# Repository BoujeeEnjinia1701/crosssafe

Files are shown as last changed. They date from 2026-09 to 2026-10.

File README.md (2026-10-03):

# CrossSafe

     

**Area:** Smart Cities · **TRL:** 3 of 9 (proof of concept on paper) · **Value-engineering target:** $350 USD (one assembly on an existing pole) · **Difficulty:** 3 of 5

A solar crossing beacon that detects a waiting pedestrian and flashes high-visibility lights to warn drivers at unsignalized crossings near schools and markets.

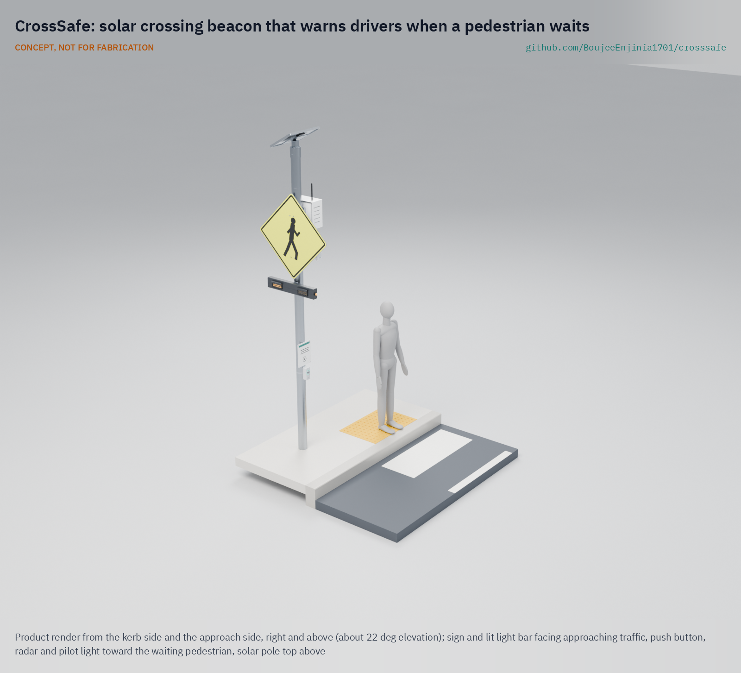
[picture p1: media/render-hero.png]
CrossSafe: solar crossing beacon that warns drivers when a pedestrian waits, product render


[Exploded render](media/render-exploded.png) · [Detail render](media/render-detail.png) · [Interactive 3D model](media/viewer.html) · [Concept blueprint (PDF)](media/concept-blueprint.pdf) · [General arrangement CRS-DWG-001 (PDF)](cad/drawings/CRS-DWG-001.pdf) · [Calculations](docs/04-calcs/01-sizing.md) · [Prototype build plan](docs/05-build-plan.md) · [Design decisions](docs/06-design-decisions.md) · [Review note](docs/REVIEW.md)

## Concept rationale

A driver yields when they see someone waiting, and a warning that appears only then is hard to ignore. CrossSafe copies the logic of the rectangular rapid flashing beacon (RRFB): two amber lights under the crossing sign that flash in a wig-wag pattern only when a pedestrian presses a button or a small radar, woken by a motion sensor, sees someone waiting at the kerb. One assembly stands on each side of the road; each has its own 20 W panel and LiFePO4 battery, and the two stay in step over a short radio link, so there is no mains connection and no cable across the road.

It is open and garage-buildable because the crossings that need it most are the ones no one will pay a signal contractor to fix. Every part is a standard sign, LED module, small solar kit, battery, IP65 box or common microcontroller, the firmware and wiring are published, and a local technician can repair it with hand tools. An open reference also lets road authorities, schools and researchers see exactly what the device does before they ask for approval to install it.

## Burning platform

About 1.19 million people die on the world's roads each year, and pedestrian deaths rose to about 274,000 in 2021, 23 % of the total, with nine in ten road deaths in low- and middle-income countries ([WHO, 2023](https://www.who.int/news/item/13-12-2023-despite-notable-progress-road-safety-remains-urgent-global-issue)). The UN General Assembly's target is to halve road deaths and injuries by 2030 ([WHO fact sheet](https://www.who.int/news-room/fact-sheets/detail/road-traffic-injuries)), and progress on pedestrians has gone the wrong way.

The problem is concentrated away from signals and after dark. In the United States, 74 % of the 7,314 pedestrians killed in 2023 died at locations that were not intersections, and 77 % died in the dark ([NHTSA, 2025](https://crashstats.nhtsa.dot.gov/Api/Public/ViewPublication/813727)). Pedestrian-activated beacons are one of the few low-cost measures with strong evidence: FHWA reports RRFBs can cut pedestrian crashes by up to 47 % and raise driver yielding to as high as 98 % ([FHWA](https://highways.dot.gov/safety/proven-safety-countermeasures/rectangular-rapid-flashing-beacons-rrfb)).

## Where it could be used

### By industry

| Industry | Use |
| --- | --- |
| Municipal roads and public works | Mid-block and uncontrolled crossings that do not qualify for a full signal |
| Education | School crossings used at the start and end of the day, often by children crossing alone |
| Markets and retail districts | Busy crossings on market days where traffic and pedestrian peaks coincide |
| Public transport | Crossings to bus and minibus stops on arterial roads |
| Hospitals, universities and campuses | Internal roads crossing between car parks, wards and buildings |
| Industrial sites and ports | Pedestrian crossings on plant roads shared with trucks and forklifts, off the public road network |

### By country or region

| Country or region | Why it matters there |
| --- | --- |
| Sub-Saharan Africa | The WHO African Region has 19 % of global road deaths with 15 % of the population and 3 % of the world's vehicles ([WHO Africa](https://www.afro.who.int/health-topics/road-safety)); walking is the main way many people travel and crossings rarely have signals |
| India | India accounts for about 10 % of road crash deaths worldwide, and most who die are pedestrians, cyclists and motorcyclists ([WHO India](https://www.who.int/india/health-topics/road-safety)) |
| South-East Asia | The WHO South-East Asia Region has the largest share of global road deaths, 28 % ([WHO, 2023](https://www.who.int/news/item/13-12-2023-despite-notable-progress-road-safety-remains-urgent-global-issue)) |
| Latin America and the Caribbean | About 145,090 road deaths in the Americas in 2021, with pedestrians, cyclists and motorcyclists rising from 39 % to 47 % of deaths since 2009 ([PAHO](https://www.paho.org/en/topics/road-safety)) |
| United States | 7,314 pedestrians killed in 2023, 74 % away from intersections ([NHTSA](https://crashstats.nhtsa.dot.gov/Api/Public/ViewPublication/813727)); RRFBs already have an FHWA interim approval ([IA-21](https://mutcd.fhwa.dot.gov/resources/interim_approval/ia21/index.htm)), so an open design could serve small towns and schools on tight budgets |
| United Kingdom | Pedestrians were 25 % of the 1,624 road deaths in Great Britain in 2023 ([Department for Transport](https://www.gov.uk/government/statistics/reported-road-casualties-great-britain-annual-report-2023/reported-road-casualties-great-britain-annual-report-2023)); local rules differ from US practice, so the flash pattern and sign are configurable |

## What sparked the idea

The starting point was a lapse in the rulebook. On December 21, 2017, FHWA terminated Interim Approval 11, which had allowed US agencies to install rectangular rapid flashing beacons, because the device had been patented and patented traffic control devices cannot be included in the MUTCD. The patents were then expressly abandoned, the RRFB concept passed into the public domain, and FHWA reinstated the device as Interim Approval 21 on March 20, 2018 ([FHWA IA-21](https://mutcd.fhwa.dot.gov/resources/interim_approval/ia21/index.htm)). A proven safety device had been off the list for three months over who owned it, and it came back only once it belonged to no one. CrossSafe takes that at its word: a beacon to the IA-21 pattern whose drawings, parts list and firmware are published so that any town, school or workshop can build and repair it.

## Problem

Pedestrians die at unsignalized crossings, and full traffic signals are costly and slow to approve. Static signs fade into the background, beacons that flash all day are ignored, and many crossings have no mains power nearby.

Full problem statement: [docs/01-problem.md](docs/01-problem.md)

## Concept

A solar crossing beacon that detects a waiting pedestrian and flashes high-visibility lights to warn drivers at unsignalized crossings near schools and markets.

One assembly stands on each side of the road: a crossing warning sign with a double-sided amber light bar and a pedestrian pilot light, a push button, a presence radar woken by a PIR sensor, and a pole-top enclosure with the battery, charger and controller under a ventilated sun shield and a 20 W panel. Both sides flash together for about 13 s per activation on a 7 m road. Only activation counts and faults are logged; no images or audio are recorded.

TRL 3 calculations ([CRS-CAL-001](docs/04-calcs/01-sizing.md)): 16.0 Wh/day at 300 activations, 7.7 days without sun, energy neutral at 1.05 peak sun hours, a 114.3 mm post at 45 % of yield in a 40 m/s gust, 53.9 °C inside the sun-shielded enclosure at 50 °C ambient, and $364 in parts per assembly on an existing pole ($728 per crossing), $14 over the $350 value-engineering target after the parts that make the design buildable and the visors and bezels on the LED heads. The existing-pole kit is limited to poles of 76 mm and larger, where the sign holds on paper at the assumed grip friction; smaller poles wait for a slip-torque test. Design decisions are recorded in [CRS-DDR-001](docs/decisions/0001-trl2-review-decisions.md), [CRS-DDR-002](docs/decisions/0002-recommendations-accepted.md) and [CRS-DDR-003](docs/decisions/0003-design-for-construction.md), and open ones, with the cost drivers, in the [design decisions register](docs/06-design-decisions.md). See the [design precis](docs/02-concept.md), [requirements](docs/03-requirements.md) and [general arrangement](cad/drawings/CRS-DWG-001.pdf).

## Key components

- Crossing warning sign, 750 mm, with a double-sided amber LED light bar (two heads per face)
- Accessible push button, a pedestrian pilot light, and a 24 GHz presence radar (presence only) switched on by a PIR sensor
- 20 W solar panel, MPPT charger and 12.8 V 12 Ah LiFePO4 battery
- Controller on the FieldNode radio core, with LED drivers and a LoRa link that keeps both sides in step
- IP65 pole-top enclosure under a ventilated sun shield
- Eight identical keyed pole saddles with stainless bands for an existing pole of 76 mm or larger (smaller poles wait for a slip-torque test of the saddle's grip), or a 114.3 mm post with an anti-rotation bolt where none exists

The working bill of materials is in [bom/bom.csv](bom/bom.csv).

## Building the prototype

The [prototype build plan](docs/05-build-plan.md) (CRS-BLD-001) shows how to make and fit every component of one assembly, the existing-pole kit, on a 3.7 m test post, with a making sketch for each made part, close-ups of the joints and a picture for every assembly step. Every part on the pole is held the same way: an aluminium saddle with a keyed V sits on the pole, a stainless band runs round the pole and across the saddle's front, and the part bolts to the saddle over the band. The work is sawing, drilling, tapping and folding aluminium bar and sheet, one small steel weldment, and wiring bought modules. It is a plan, not yet built; building to it is TRL 4 work.

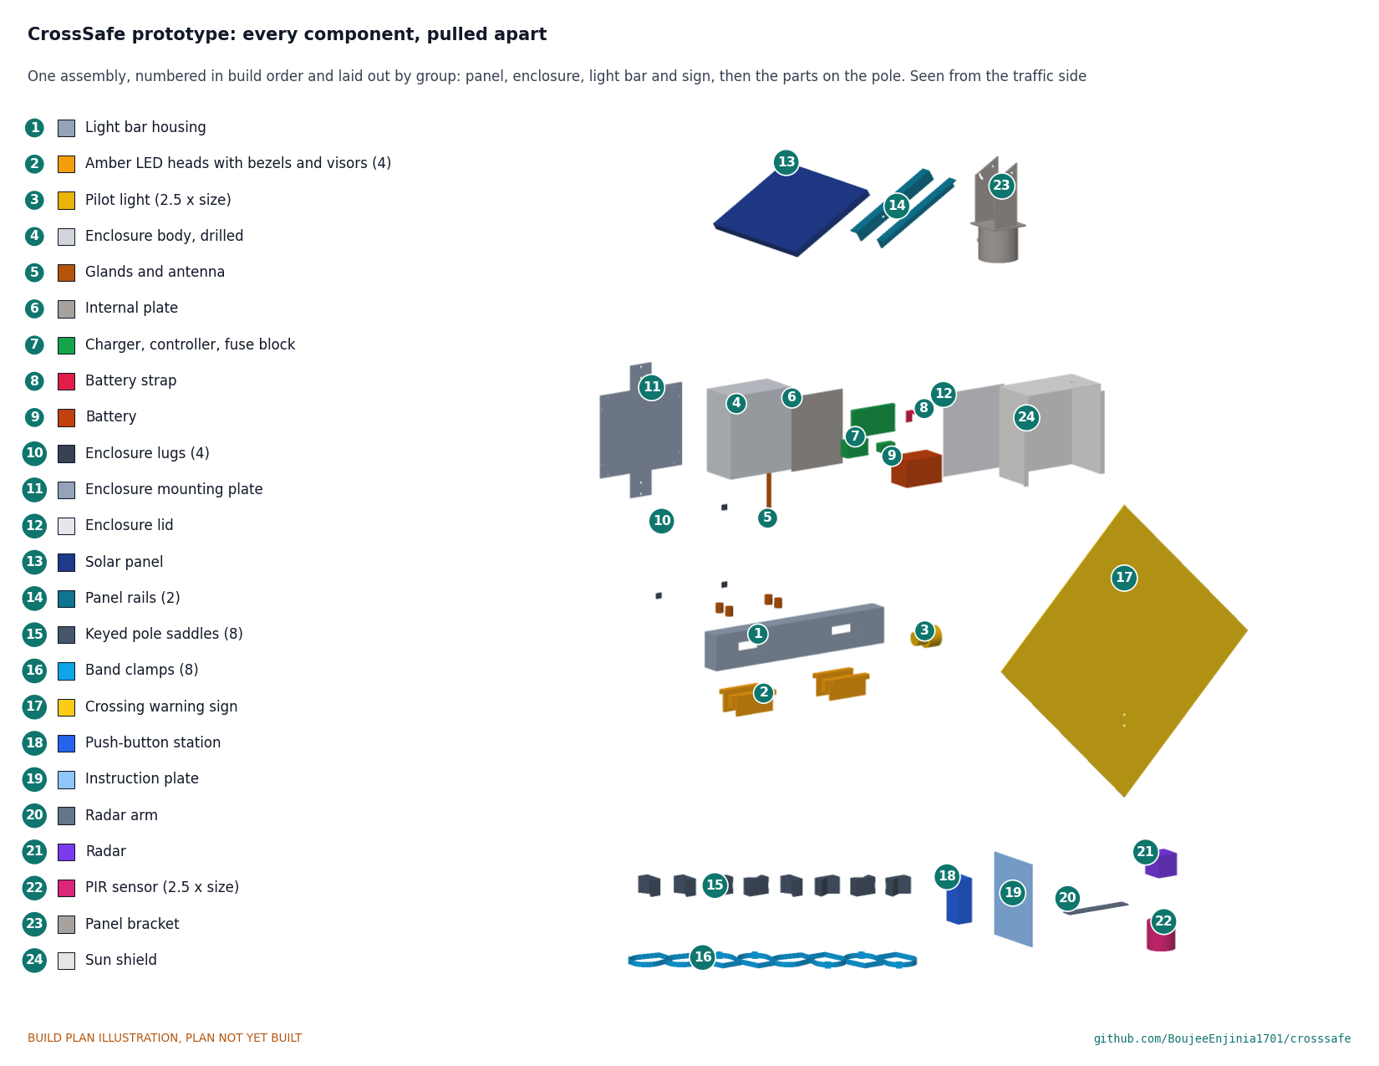
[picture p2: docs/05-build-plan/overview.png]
CrossSafe prototype: every component pulled apart and numbered in build order


## Safety

> A research prototype; traffic control devices must meet local standards and road authority approval before use on a public road. Pedestrians must still check that drivers have stopped. Lithium cells can overheat, vent and burn. Use protected cells or LiFePO4, fuse every pack, charge only within the cell maker's limits and never leave a first build charging unattended. Street furniture and pole mounts must be installed only with the asset owner's permission, by trained crews, with fall protection and traffic management as local rules require. The post, clamps, footing or host pole must pass a wind load check by a qualified engineer before installation; sign and panel edges are sharp.

## Repository layout

| Folder | Contents |
| --- | --- |
| `docs/` | Problem, concept, requirements, calculations and design decisions |
| `cad/src/` | build123d Python source, the source of truth for all geometry |
| `cad/step/`, `cad/stl/` | Exported models for FreeCAD, other CAD tools and printing |
| `cad/drawings/` | 2D sketches and dimensioned drawings |
| `bom/` | Bill of materials |
| `electronics/` | KiCad schematics and PCB layouts |
| `firmware/` | Microcontroller code |
| `media/` | Renders, perspectives and photos |
| `build-log/` | Dated prototyping notes |

## Documentation

Controlled documents follow the portfolio [documentation standard](.kit/STANDARDS.md). Each carries a document ID (CRS-PRC-001 for the precis), a version and a revision history. Branded PDFs are built with `python .kit/render.py` and attached to GitHub Releases when a document is tagged, for example `CRS-PRC-001/v1.0`.

## Credits

Designed by Amish Chadha. See [CONTRIBUTORS.md](CONTRIBUTORS.md) for roles. To cite this design, use [CITATION.cff](CITATION.cff) (GitHub shows it as "Cite this repository").

AI assistance (Claude) was used to accelerate concept renders, prototype documentation and first-pass sizing calculations. Design direction and all decisions are Amish Chadha's, recorded in this repository's decision records (`docs/decisions/`).

## Licenses

- **Hardware** (CAD, drawings, BOM, electronics): [CERN-OHL-S v2](LICENSE)
- **Software** (firmware, scripts, notebooks): [MIT](LICENSE-SOFTWARE)

A project of the [Design Molecule](https://designmolecule.com) lab.

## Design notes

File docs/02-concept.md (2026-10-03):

---
doc_id: CRS-PRC-001
title: CrossSafe design precis
project: CrossSafe
doc_type: Design precis
version: "0.8"
status: Draft
date: '2026-10-02'
author: Amish Chadha
license: CERN-OHL-S-2.0
revisions:
- version: "0.1"
  date: '2026-09-25'
  author: Amish Chadha
  change: Initial scaffold
- version: "0.2"
  date: '2026-09-25'
  author: Amish Chadha
  change: TRL 2 concept (how it works, components, first-order numbers, safety, open questions)
- version: "0.3"
  date: '2026-09-25'
  author: Amish Chadha
  change: TRL 3 update; design choices adopted for TRL 3 work (CRS-DDR-001), PIR gating, pilot light, 114.3 mm post, numbers from CRS-CAL-001, model and drawing CRS-DWG-001
- version: "0.4"
  date: '2026-09-25'
  author: Amish Chadha
  change: Recommendations accepted by Amish (DDR-002)
- version: "0.5"
  date: '2026-09-30'
  author: Amish Chadha
  change: Constructable design (CRS-DDR-003) with keyed saddles and bands for every part on the pole, mounting plate, radar arm, panel bracket and rails; numbers from CRS-CAL-001 v0.3
- version: "0.6"
  date: '2026-10-01'
  author: Amish Chadha
  change: Budget treated as a value-engineering target
- version: "0.7"
  date: '2026-10-02'
  author: Amish Chadha
  change: "Decisions of 2026-10-02: existing-pole kit limited to 76 mm and up until a slip-torque test; panel socket for free-topped 114 mm poles; first pilot partner candidate"
- version: "0.8"
  date: '2026-10-02'
  author: Amish Chadha
  change: Bezels and visors on the LED heads; pole range 76 to 114.3 mm; cost $364.00 per assembly
---

# CrossSafe design precis

## Summary

CrossSafe is a pair of pole-mounted, solar-powered warning beacons, one on each side of an unsignalized crossing. When a pedestrian presses the button or a small radar sensor sees someone waiting at the kerb, both assemblies flash two amber lights per face under the crossing warning sign for about 13 s, and a small pilot light confirms to the pedestrian that the warning is on. Each assembly runs from a 20 W panel and a 12.8 V 12 Ah LiFePO4 battery, a low-power PIR sensor switches the radar on only when something moves nearby, and the two sides stay in step over a short LoRa link, so no trench or cable across the road is needed. The TRL 3 calculations (CRS-CAL-001) give 16.0 Wh/day of use at 300 activations, 7.7 days without sun, and $360.00 in parts for one assembly on an existing pole, $10.00 over its budget after the parts that make the design buildable (CRS-DDR-003). A ventilated sun shield keeps the battery below its discharge limit, and an anti-rotation bolt (new posts) or keyed saddles (existing poles) stop the sign turning in a storm; only poles under about 70 mm remain at risk.

The concept follows the rectangular rapid flashing beacon (RRFB), which FHWA lists as a proven safety countermeasure ([FHWA](https://highways.dot.gov/safety/proven-safety-countermeasures/rectangular-rapid-flashing-beacons-rrfb)), and uses the US Interim Approval IA-21 as its reference for light size, flash pattern, night dimming and the optional pilot light ([FHWA IA-21](https://mutcd.fhwa.dot.gov/resources/interim_approval/ia21/index.htm)). It is an open reference design, not a certified traffic control device.

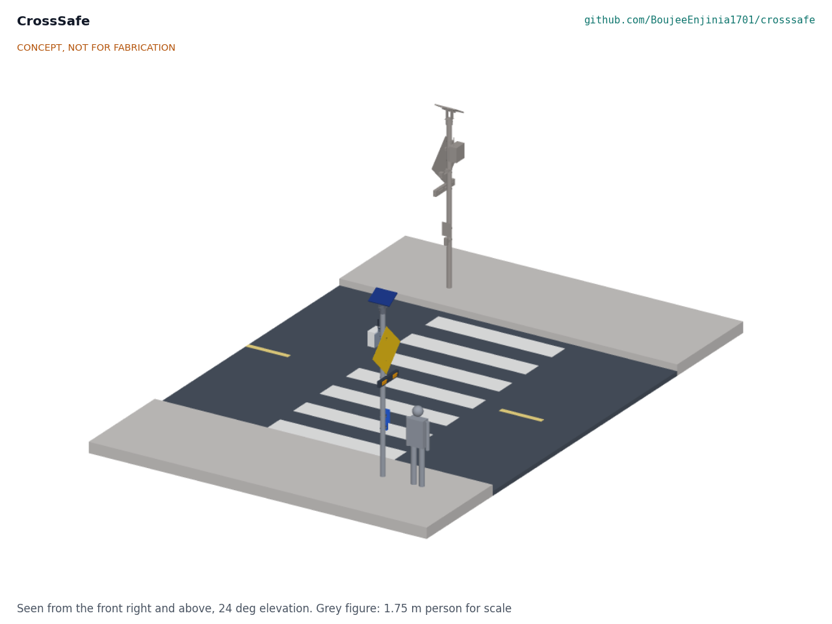
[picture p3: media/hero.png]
Figure 1. Hero render: one CrossSafe assembly on the near sidewalk of a 7 m two-lane crossing, the far-side assembly in grey, and a 1.75 m person for scale.


## How it works

1. **Idle.** The controller sleeps with its radio listening, the button is armed, and a PIR sensor watches for movement near the kerb. When the PIR sees motion it switches on the radar, which watches a waiting zone of about 1.5 x 2 m; the radar goes off again when nothing has moved for a set time. Passive detection can be switched off where it is not allowed. The battery charges from the panel.
2. **Trigger.** A button press, or a person detected in the waiting zone for 1 s or more, wakes the controller.
3. **Synchronize.** The controller sends a short LoRa packet to the far-side assembly (and listens for the same from it). Both start flashing within 48 ms, or 244 ms if two packets are lost (CRS-CAL-001).
4. **Warn.** Two amber heads per face flash in the IA-21 wig-wag sequence, 75 sequences per minute, for the site's set time (crossing length / 0.9 m/s + 5 s, 12.8 s for 7 m), dimmed at night. A new trigger extends the time. The pilot light on the kerb end of the light bar confirms to the pedestrian that the warning is on, and the button gives a click and a tactile pulse.
5. **Log.** The controller counts activations and records faults and battery state. It stores no images or audio; the radar reports presence only.

Figure 2 shows the daily energy flow and Figure 3 the parts. The general arrangement is drawing CRS-DWG-001 (`cad/drawings/`), generated from the parametric model `cad/src/model.py`.

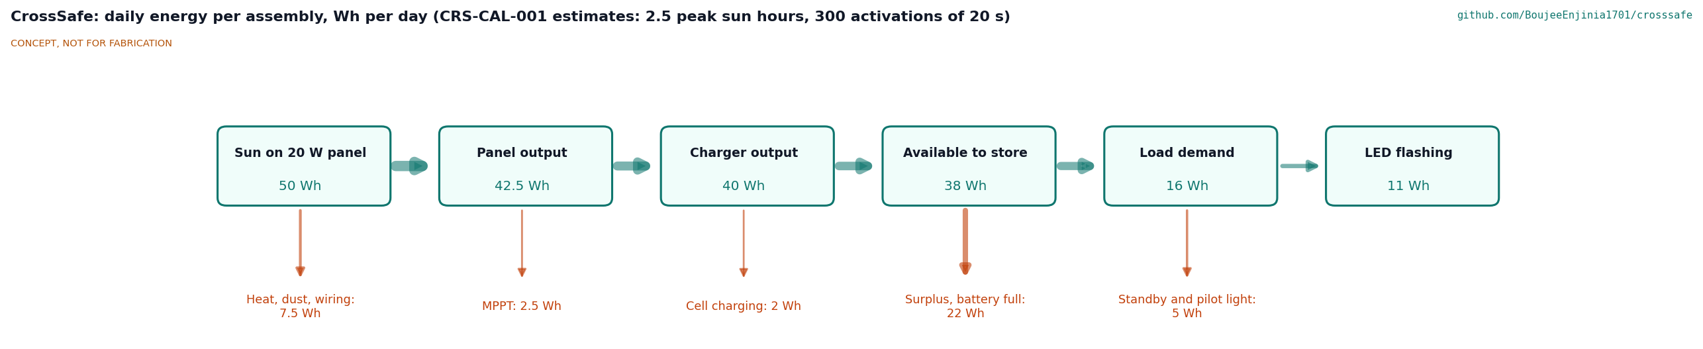
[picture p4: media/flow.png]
Figure 2. Daily energy flow for one assembly, Wh per day. All values are CRS-CAL-001 estimates (2.5 peak sun hours, 300 activations of 20 s).


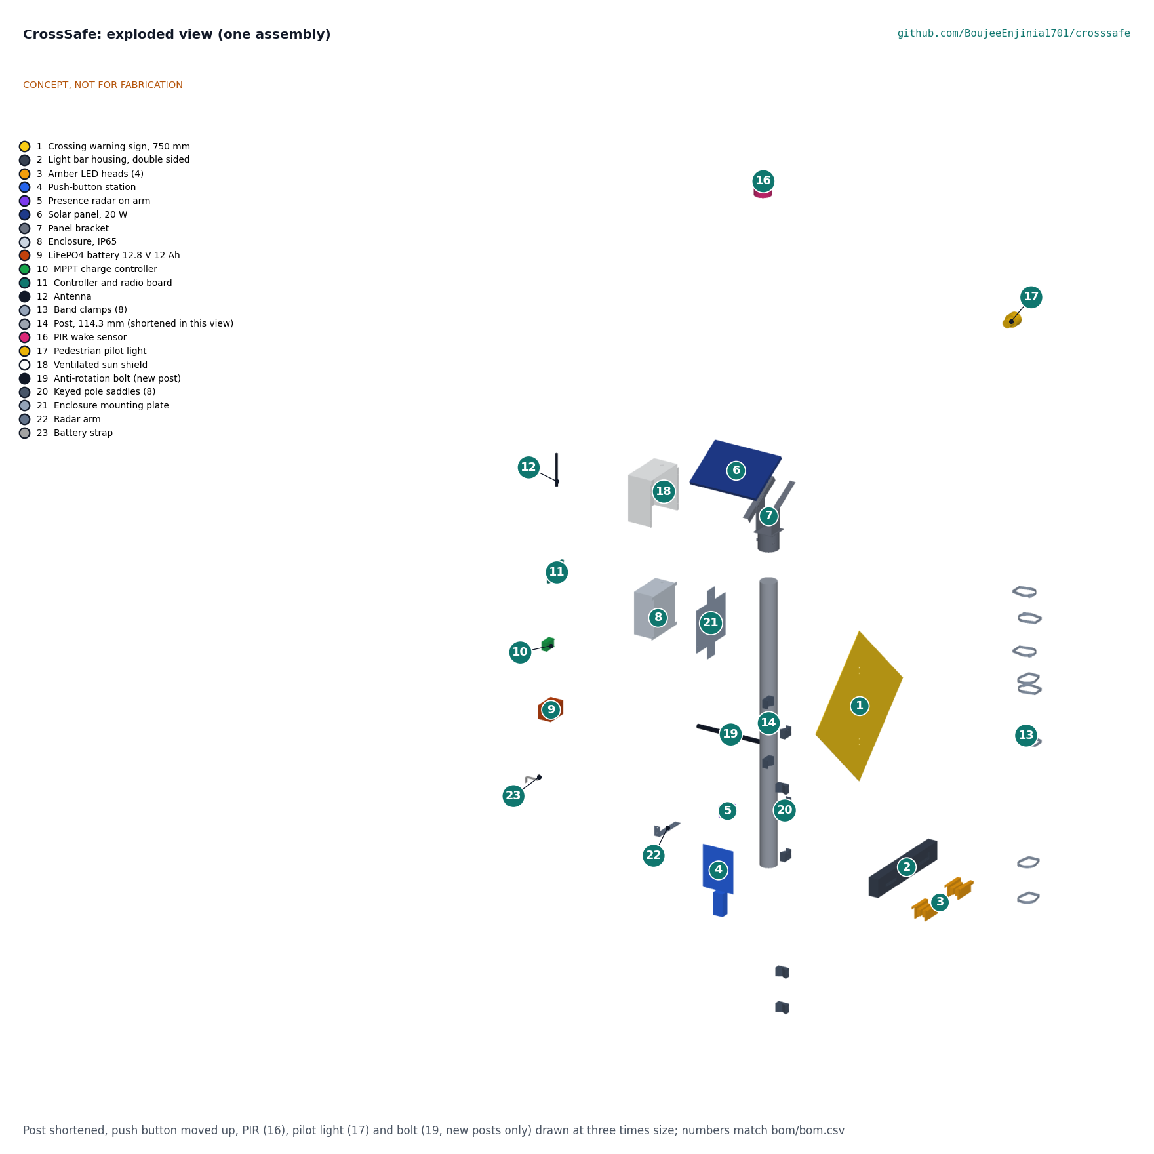
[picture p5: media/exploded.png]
Figure 3. Exploded view of one assembly; callout numbers match .


## Main components

Table 1. Components of one assembly. Numbers match the exploded view and `bom/bom.csv` (line 15, wiring, glands and fixings, has no callout). Each part is made and fitted as the build plan CRS-BLD-001 (`docs/05-build-plan.md`) shows.

| No. | Component | Concept choice |
| --- | --- | --- |
| 1 | Crossing warning sign | 750 mm diamond, retroreflective, local sign design |
| 2 | Light bar housing | Folded 2 mm aluminium channel with a screwed bottom cover and riveted end caps, double sided, 720 x 130 x 70 mm, bottom at 2.1 m |
| 3 | LED heads (4) | Amber, 140 x 62 mm lens (127 x 51 mm minimum), two per face, with daylight and night levels; each has a bezel frame and a 26 mm hood visor with a drip lip, bought with the head |
| 4 | Push-button station | Vandal-resistant piezo button with acknowledgement tone and tactile arrow, instruction plate, at about 1.0 m |
| 5 | Presence radar | 24 GHz presence sensor on the radar arm (22) at 2.6 m, aimed at the waiting zone, powered only when the PIR sees motion |
| 6 | Solar panel | 20 W monocrystalline, about 500 x 360 mm, tilted about 30 degrees toward the equator |
| 7 | Panel bracket | Welded steel socket, cap and cheeks on the post top, with two aluminium rails and a 20 to 40 degree tilt slot |
| 8 | Enclosure | IP65 polycarbonate, 150 x 260 x 300 mm, membrane vent, internal plate, lug kit, 2.85 to 3.15 m, behind the post on its mounting plate (21) |
| 9 | Battery | LiFePO4 12.8 V 12 Ah (about 154 Wh) with internal BMS |
| 10 | Charge controller | Small MPPT controller with a LiFePO4 profile and low-temperature charge cut-off |
| 11 | Controller and radio board | FieldNode radio core (STM32WL-class LoRa module) in point-to-point mode, four LED drivers with night dimming, real-time clock, fault indicator |
| 12 | Antenna | Short whip on the enclosure roof |
| 13 | Band clamps | Eight 19 x 0.76 mm stainless bands with buckles, one at each saddle |
| 14 | Post | Existing pole first; where a new post is needed, 114.3 x 3.6 mm galvanized steel, 3.7 m above the sidewalk, 1.8 m in a 500 mm footing |
| 16 | PIR wake sensor | Low-power passive infrared sensor under the radar; switches the radar on |
| 17 | Pedestrian pilot light | Small amber light on the kerb end of the light bar, where local rules allow |
| 18 | Sun shield | Ventilated white aluminium shield over the enclosure roof and three walls, 25 mm air gap, open at the bottom |
| 19 | Anti-rotation bolt | M10 stainless bolt through the sign, the upper sign saddle and the post; new posts only |
| 20 | Keyed pole saddles | Eight identical aluminium blocks with a keyed 120 degree V, a band groove and two M8 holes; every part on the pole bolts to one; fit 76 to 114.3 mm poles (60 to 75 mm only after a slip-torque test) |
| 21 | Enclosure mounting plate | 4 mm aluminium, 350 x 300 mm with saddle tabs above and below; carries the enclosure lugs and the sun shield |
| 22 | Radar arm | 40 x 5 mm aluminium bar bent to an L, on its own saddle; radar on top, PIR underneath |
| 23 | Battery strap | Bent aluminium strip holding the battery on the enclosure floor |

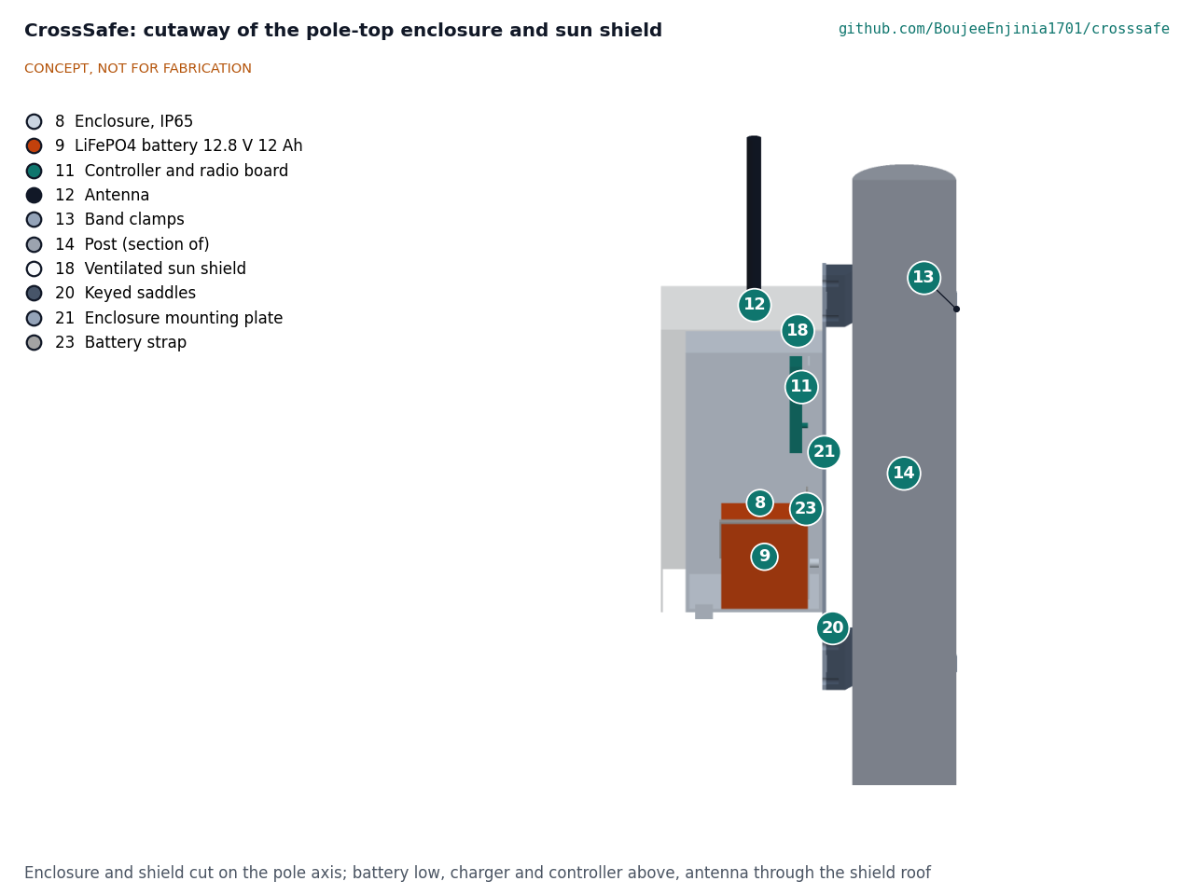
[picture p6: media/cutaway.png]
Figure 4. Cutaway of the pole-top enclosure and sun shield: battery low, charger and controller above, antenna through the shield roof.


## Key design choices

Each choice below was decided by Amish on 2026-09-25 by accepting the recommendations (CRS-DDR-001 and CRS-DDR-002).

- **RRFB-style amber beacons, not a signal (D4).** Amber warning lights with the standard sign ask drivers to yield; they do not claim to stop traffic, which keeps the device in a simpler approval class in most places. IA-21 is the baseline; the flash pattern is configurable for other jurisdictions.
- **Button plus passive detection, gated by a PIR (D2, D5).** The button is the reliable, accessible trigger; radar catches people who do not press it and can be switched off where passive detection is not allowed. The PIR keeps the radar off when nothing moves, which is what brings autonomy above 5 days. The radar reports presence only, which keeps images and audio off the device.
- **Radio sync instead of a cable (D6).** A LoRa point-to-point link avoids cutting the road. If the link drops, each side still flashes on its own trigger and reports a fault.
- **Own 12 V power system, FieldNode radio core (D7).** The LED load (up to about 26 W at the instant all four heads are lit) is far beyond the FieldNode power stage (6 W panel, 3.2 V cell), so CrossSafe uses a 12.8 V LiFePO4 battery with a built-in BMS. The controller reuses FieldNode's STM32WL-class radio and logging design. CellGuard, the lab's open BMS for 4 to 16 LiFePO4 cells, is a later option in place of the drop-in battery's closed BMS.
- **Existing poles first; 114.3 mm where a new post is needed (D3).** The band clamps and saddles are used only on poles of 76 to 114.3 mm until a slip-torque test confirms the keyed saddle's grip; a third saddle and band at the sign then brings 60 to 75 mm poles back (decided 2026-10-02). The prototype's panel socket fits free-topped poles of about 114 mm; a side-of-pole panel arm is designed once the pilot site's poles are known. The new-post variant meets the wind target with margin.
- **Pedestrian pilot light (D8).** IA-21 permits a small pilot light on the beacon or push button; it is included where local rules allow.
- **Sun shield on the enclosure (CRS-DDR-002).** A ventilated white shield cuts the enclosure's rise in full sun from 14.7 to 3.9 K when dusty, so the battery stays below its discharge limit and keeps charging on hot days. Placing the enclosure in the panel's shadow is to be considered when the bracket is detailed.
- **Anti-rotation detail (CRS-DDR-002).** An M10 through-bolt locks the sign and its upper saddle to a new post; on existing poles, where drilling needs the owner's consent, keyed saddles with serrated grip faces raise the clamp friction. Band tension and grip are to be measured at TRL 4, which is on hold.
- **One way of fixing everything to the pole (CRS-DDR-003).** Eight identical keyed saddles, each pulled onto the pole by a stainless band that runs across its front, carry the sign, light bar, button, instruction plate, radar arm and enclosure; each part bolts to its saddle over the band. The design is open for Amish's review.
- **Electronics high on the pole.** The enclosure bottom at 2.85 m and the panel at the top deter theft and keep cables out of reach.

## Key numbers (CRS-CAL-001)

The TRL 2 first-order estimates have been replaced by the TRL 3 calculation note CRS-CAL-001, which states every assumption and prints every figure from `docs/04-calcs/sizing.py`. The main results:

- **Flash time.** 12.8 s for a 7 m crossing; the energy case uses 20 s, enough for crossings up to 13.5 m.
- **Energy.** Each head is lit 25 % of each IA-21 sequence, so the LEDs use 10.99 Wh/day at 300 activations. Standby is 187 mW (4.49 Wh/day) with the PIR gating the radar. The daily load is 16.0 Wh, against 38.0 Wh stored in the worst month; break-even is 1.05 peak sun hours, and the battery refills from 20 % in 2.05 days at 5 peak sun hours.
- **Autonomy.** 122.9 Wh usable gives 7.7 days without sun, 5.4 days at -20 °C and 6.2 days at end of life.
- **Heat.** Unshielded, the enclosure would run 9.6 K (clean) to 14.7 K (dusty) above ambient in full sun and a dusty box would reach 64.7 °C at 50 °C ambient. With the sun shield the rise is 3.9 K: 53.9 °C inside at 50 °C ambient, and charging continues up to 41.1 °C ambient (R8 met on paper).
- **Latency and link.** 48 ms side to side, 244 ms with two retries; about 60 dB of link margin across the road with a bus in the way.
- **Wind.** A 40 m/s gust gives 3.52 kN·m at the base. The 114.3 x 3.6 mm post reaches 105 MPa, 45 % of S235 yield; an 88.9 x 4 mm post would reach 65 %. The sign's 175 N·m of torsion is carried by the through-bolt on new posts (12 % of bearing) and by keyed saddles on existing poles of 76 mm and larger, which hold at an assumed grip friction of 0.4 (R9); smaller poles wait for a slip-torque test. A 500 mm footing needs about 1.8 m of embedment in clay (screening).
- **Cost.** Value-engineering target: $350 per assembly on an existing pole (a hypothetical control target, not a limit). Estimated cost of the constructable design: $364.00 per assembly ($14.00 over the target) and $728.00 per crossing ($28.00 over the $700 target); $437.00 and $874.00 with new posts (see `bom/bom.csv`). Cost drivers and savings worth trying are in the Value engineering section of `docs/06-design-decisions.md`. The $750 value-engineering target for a two-sided site trial applies when a trial starts (on hold with TRL 4).

## Safety

> **Safety:** CrossSafe is a research prototype. A traffic control device must meet local standards and have road authority approval before use on a public road. A beacon that fails dark, flashes when no one is there, or gives pedestrians false confidence can cause harm; pedestrians must still check that drivers have stopped.

> **Safety:** Lithium cells can overheat, vent and burn. Use LiFePO4 with a BMS, fuse the battery output close to the terminal, charge only between 0 and 45 °C cell temperature, and shade the enclosure. Never charge a damaged or swollen battery.

> **Safety:** Installing on a pole next to live traffic is work at height and work in the road. Use trained crews, traffic management and fall protection as local rules require, keep clear of overhead power lines, and mount only with the asset owner's permission. A post, sign or panel that falls can kill. CRS-CAL-001 is a screening check only: clamp torsion is at risk on poles under about 70 mm, and a qualified engineer must check the post, clamps, footing or host pole to the local code before installation.

> **Safety:** Sign and panel edges are sharp and heavy; handle with gloves and a second person.

## Open questions

- [ ] Pilot jurisdiction and its rules for beacon color, flash pattern, sign design and mounting height. First candidate to approach (2026-10-02): a United States city traffic engineering department with a Safe Routes to School or Vision Zero programme, in a North Texas city near the team; nothing is agreed.
- [ ] Measured LED head power and intensity for the chosen modules, and whether 6 W per head is enough in full sun.
- [ ] Radar false-trigger rate with passing pedestrians, cyclists, animals and rain.
- [ ] Radio range and reliability across the road with parked vehicles and buses in the path, and licence-free band rules in the pilot country.
- [ ] Measured enclosure temperature in full sun with the shield fitted, and whether the enclosure can sit in the panel's shadow (CRS-CAL-001, section C).
- [ ] Measured band tension and keyed saddle grip (a slip-torque test), which must pass before the existing-pole kit is used below 76 mm with a third saddle and band (R9; CRS-DDR-002, N1, decided 2026-10-02); host pole checks by the owner; local foundation design.
- [ ] Whether the pedestrian-facing confirmation light is allowed locally.

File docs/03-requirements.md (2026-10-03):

---
doc_id: CRS-REQ-001
title: CrossSafe requirements
project: CrossSafe
doc_type: Requirements
version: "0.8"
status: Draft
date: '2026-10-02'
author: Amish Chadha
license: CERN-OHL-S-2.0
revisions:
- version: "0.1"
  date: '2026-09-25'
  author: Amish Chadha
  change: Initial scaffold
- version: "0.2"
  date: '2026-09-25'
  author: Amish Chadha
  change: First measurable requirements for TRL 2, with status against the concept estimates
- version: "0.3"
  date: '2026-09-25'
  author: Amish Chadha
  change: TRL 3 status from CRS-CAL-001; R15 redefined to the existing-pole assembly (CRS-DDR-001 D1); R1, R9 and R11 updated for D3, D4 and D8
- version: "0.4"
  date: '2026-09-25'
  author: Amish Chadha
  change: Recommendations accepted by Amish (DDR-002)
- version: "0.5"
  date: '2026-09-30'
  author: Amish Chadha
  change: Status from CRS-CAL-001 v0.3 for the constructable design (CRS-DDR-003); R15 now not met on paper
- version: "0.6"
  date: '2026-10-01'
  author: Amish Chadha
  change: Budget treated as a value-engineering target
- version: "0.7"
  date: '2026-10-02'
  author: Amish Chadha
  change: "R10 restated on 2026-10-02: existing-pole kit 76 to 114 mm until a slip-torque test, panel socket for free-topped poles of about 114 mm; no status changed"
- version: "0.8"
  date: '2026-10-02'
  author: Amish Chadha
  change: R9 met on paper for 76 to 114.3 mm poles; R10 and R15 figures updated (cost $364.00 per assembly)
---

# CrossSafe requirements

These requirements are checked by calculation in CRS-CAL-001 at TRL 3. Targets are still proposals, not yet validated with users or a road authority, and will be revised after co-design (see CRS-PRB-001). Where a local rule is stricter, the local rule wins. The design choices behind them were accepted by Amish on 2026-09-25 (CRS-DDR-001 and CRS-DDR-002).

The **design case** is a marked crossing on a two-lane road 7 m kerb to kerb, one CrossSafe assembly on each side, 300 activations of 20 s per day, 2.5 peak sun hours per day in the worst month, and an ambient range of -20 to +50 °C.

Table 1. Requirements and status at TRL 3 (CRS-CAL-001 v0.4, Table 5).

| ID | Requirement | Target | Verification (TRL 3 or later) | Status at TRL 3 |
| --- | --- | --- | --- | --- |
| R1 | Warning light geometry and pattern | Two amber rectangular indications per face, each at least 127 x 51 mm (5 x 2 in); the FHWA IA-21 wig-wag sequence at 75 flashing sequences per minute; pattern set in firmware for other jurisdictions; an optional pedestrian pilot light where allowed | Design review against the pilot jurisdiction's rules | Met by design (140 x 62 mm lenses) |
| R2 | Visibility | Indications distinguishable by a driver at 100 m or more in direct sun (IA-21 cites SAE J595 Class 1 yellow peak intensity) and not glaring at night (automatic dimming) | Photometric calculation from LED data; later field check | Not verifiable at TRL 3 (screening: about 3,939 cd per head) |
| R3 | Activation | Push button and passive presence detection; both sides of the road flash within 0.5 s of a trigger on either side | Timing budget; later bench test | Met on paper (48 ms; 244 ms with two retries) |
| R4 | Flash duration | Set per site from crossing length / 0.9 m/s + 5 s, adjustable 10 to 40 s; a new trigger while flashing extends the time | Firmware review | Met by design (12.8 s for 7 m) |
| R5 | Detection quality | Passive detection triggers for a person waiting 1 s or more in the waiting zone; false activations 5 % or fewer of all activations; missed waiting pedestrians 2 % or fewer | Site trial with manual counts | Not verifiable at TRL 3 |
| R6 | Autonomy without sun | 5 days or more of design-case use from a full battery | Energy calculation | Met on paper (7.7 days; 5.4 at -20 °C) |
| R7 | Energy balance | Energy neutral at 2.5 peak sun hours; recover from 20 % to full in 3 days or fewer at 5 peak sun hours | Solar yield calculation | Met on paper (break-even 1.05 h; recovery 2.1 days) |
| R8 | Environment | Enclosures and connectors IP65 or better; operate -20 to +50 °C ambient; battery charges only at 0 to 45 °C cell temperature | Datasheets and heat balance; later spray and thermal tests | Met on paper with the sun shield (53.9 °C inside at 50 °C ambient when dusty; charging to 41.1 °C ambient) |
| R9 | Structure | Post and clamps carry the sign and panel in a 40 m/s gust with stress 60 % or less of yield; new posts are 114.3 x 3.6 mm (CRS-DDR-001 D3); the sign cannot rotate on its pole (anti-rotation bolt on new posts, keyed saddles on existing poles, CRS-DDR-002) | Wind load calculation | **Met on paper for poles of 76 to 114.3 mm: post 45 % of yield and bolt 12 % of bearing; keyed saddles resist 191 N·m on a 76 mm pole against 175 N·m, at assumed friction and band tension** |
| R10 | Mounting | Fits the project's own post or an existing 76 to 114 mm pole with band clamps (60 to 75 mm poles only after a slip-torque test confirms the keyed saddle's grip, with a third saddle and band at the sign); the prototype's panel socket fits free-topped poles of about 114 mm; sign bottom at 2.1 m or more (or local rule); two-person crew installs one assembly in 2 h or less | Design review; later timed trial | Not verifiable at TRL 3 (fit met on free-topped poles of about 114 mm; install estimate 120 min, at the limit) |
| R11 | Accessibility | Push button 0.9 to 1.1 m above the walking surface, operable with 22 N or less, with an audible and tactile acknowledgement and a pedestrian-facing pilot light | Design review with disability groups | Met by design (button at 1.05 m), to be checked in co-design |
| R12 | Fail-safe behavior | Never flashes continuously; a fault (low battery, open LED, lost radio link) is shown on a maintenance indicator and logged; with the link lost, each side still flashes on a local trigger | Firmware review; fault injection later | Met by design |
| R13 | Privacy | No images or audio are recorded or leave the device; only activation counts, faults and battery state are logged or sent | Design review | Met by design |
| R14 | Theft and vandal resistance | Battery, charger and controller 2.8 m or more above the walking surface; security fasteners; no exposed cables below 2.5 m | Design review | Met by design (enclosure bottom 2.85 m; sensing head 2.515 m and up) |
| R15 | Affordable | Parts for one assembly on an existing pole $350 or less (the prototype `budget_usd` covers, CRS-DDR-001 D1); parts for a two-sided crossing on existing poles $700 or less. Crossings that need new posts are costed and reported, not held to this target | Priced BOM (`bom/bom.csv`) | **Over the value-engineering target by $14.00 per assembly ($364.00 against $350) and $28.00 per crossing ($728.00 against $700)**; new posts $437.00 and $874.00 |

## Requirements at risk or not verifiable

One requirement is over its value-engineering target on paper (R15, cost) and three need evidence that a paper study cannot give.

- **R15 over the value-engineering target after the design for construction (CRS-DDR-003).** The saddles, mounting plate, panel bracket, radar arm, battery strap and fixings that make every part buildable and fixed add $28.00, and the bezels and visors on the four LED heads add $4.00: the estimated cost of one assembly on an existing pole is $364.00 against the $350 target ($14.00 over), and of a crossing $728.00 against $700 ($28.00 over). The target is a hypothetical control target, not a limit; cost drivers and savings worth trying are in the Value engineering section of the design decisions register.

- **R9 met on paper on poles of 76 mm and larger.** The 114.3 x 3.6 mm post meets the stress target at 45 % of yield, and a 1,800 mm embedment in a 500 mm footing is a screening size. On new posts the M10 through-bolt stops the sign rotating with a wide margin. On existing poles the keyed saddles hold on poles of about 70 mm and larger at an assumed grip friction of 0.4, so R9 is met on paper for the 76 to 114.3 mm range the existing-pole kit is now limited to (decided 2026-10-02, CRS-DDR-002, N1). The friction and band tension are assumptions, and the 191 N·m resistance on a 76 mm pole is only 9 % above the 175 N·m load. A slip-torque test on the keyed saddle must confirm the grip before the kit is used below 76 mm, when a third saddle and band would bring 60 to 75 mm poles back. On existing poles the host pole must carry about 2.5 kN·m more at the sidewalk, which the owner must confirm.
- **R8 met on paper after the sun shield (CRS-DDR-002).** Unshielded, a dusty enclosure ran 14.7 K above ambient and reached 64.7 °C at 50 °C ambient; with the ventilated shield the rise is 3.9 K and the interior 53.9 °C, below the typical 60 °C discharge limit. The shield factor is borrowed, not measured.
- **R2, R5 and R10 are not verifiable at TRL 3.** R2 and R5 decide whether drivers respond and whether passive detection is trusted.
- **R6, not met at TRL 2, is now met on paper** after the PIR gating (D2).

## Assumptions

The full list is in CRS-CAL-001, Table 1. The main ones are:

- LED heads draw about 6 W each when lit in daytime and are lit 25 % of each IA-21 sequence; LED drivers are about 91 % efficient.
- Standby about 187 mW: radio in continuous receive and controller about 23 mW, 12 V quiescent about 13 mW, charger about 51 mW, radar 0.4 W on 25 % of the day under PIR gating.
- Solar system efficiency about 76 % from panel rating to energy stored (panel heat and dust 0.85, MPPT 0.94, cell charge 0.95).
- Walking speed of 0.9 m/s allows for children and older people; the US MUTCD basis is faster, and local rules decide.
- Gust wind speed of 40 m/s and a drag coefficient of 1.2 for every part; S235 steel for the post; band tension 1,000 N; keyed saddle grip friction 0.4; a ventilated shield passes 25 % of the solar gain.

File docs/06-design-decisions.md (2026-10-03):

---
doc_id: CRS-DEC-001
title: CrossSafe design decisions register
project: CrossSafe
doc_type: Design decisions register
version: "0.4"
status: Draft
date: '2026-10-02'
author: Amish Chadha
license: CERN-OHL-S-2.0
revisions:
- version: "0.1"
  date: '2026-09-30'
  author: Amish Chadha
  change: Register opened with the open decisions from the review note, CRS-DDR-001 to CRS-DDR-003 and the build plan work
- version: "0.2"
  date: '2026-10-01'
  author: Amish Chadha
  change: Budget treated as a value-engineering target
- version: "0.3"
  date: '2026-10-02'
  author: Amish Chadha
  change: "Amish approved the recommendations for all open decisions 1 to 8 on 2026-10-02 (CRS-DDR-003 accepted; existing-pole kit limited to 76 mm and up); moved to decisions made"
- version: "0.4"
  date: '2026-10-02'
  author: Amish Chadha
  change: "Value engineering figures updated for the head bezels and visors: USD 364.00, USD 14.00 over the target"
---

# CrossSafe design decisions register

Every design decision still to be made, and every decision made, in one place. Each decision is argued in full in its decision record under `docs/decisions/`; this register is the index Amish works from. The build plan (`docs/05-build-plan.md`) describes the design as it stands and does not list open decisions.

## Open decisions

None. All open decisions were decided on 2026-10-02.

## To confirm when parts are bought

| # | What to confirm | Why it matters | Source |
| --- | --- | --- | --- |
| 1 | The enclosure model: its internal plate and boss positions, its lug kit, and that the lid is on the 260 x 300 face away from the back | They set the internal plate layout, the lug holes in the mounting plate and the shield fit | CRS-DDR-003, P4 |
| 2 | The solar panel frame has a flat back lip at least 15 mm wide on its long edges | The rails bolt through it | CRS-DDR-003, P8 |
| 3 | Each LED head's flange covers a 128 x 50 mm window, its body is no deeper than 25 mm, and its screw pattern | They set the light bar windows and leave 16 mm between facing heads | CRS-DDR-003, P3 |
| 4 | The push-button station fixes to a flat face with two bolts 40 mm apart (or an adaptor plate is needed) | It bolts to a saddle's two tapped holes | CRS-DDR-003, P9 |
| 5 | The radar housing's two base screws are 50 mm apart and the PIR's neck is 12 mm or less | They set the radar arm's holes | CRS-DDR-003, P7 |
| 6 | The battery, charger and controller board fit the sizes in the build plan (151 x 95 x 98, 40 x 90 x 60, 180 x 100 mm) | The internal layout and the battery strap are drawn to them | CRS-DDR-003, P4 |
| 7 | The band and buckle reach 1,000 N of tension with the banding tool, and the keyed saddle's grip friction is about 0.4 | CRS-CAL-001 assumes both for the sign torsion; until a slip-torque test confirms them the existing-pole kit is limited to poles of 76 mm and larger (decided 2026-10-02) | CRS-CAL-001, [G6c] |
| 8 | The test post's top is square and open (or capped flush) so the bracket cap sits on it | The socket's cap rests on the pole's top edge | CRS-DDR-003, P8 |

## Value engineering

Value-engineering target: USD 350 (a hypothetical control target, not a limit). Estimated cost of the constructable design: USD 364.00 (USD 14.00 over the target). A crossing needs two assemblies: USD 728.00 against a target of USD 700; with new posts USD 437.00 and USD 874.00, which are costed and reported, not held to the target.

Main cost drivers: the eight keyed saddles in place of two (USD 18.00 more), the enclosure mounting plate (USD 8.00), the panel bracket (USD 6.00 more), the radar arm and battery strap (USD 3.00) and the fixings (USD 4.00 more) and the bezels and visors bought with the LED heads (USD 4.00), less the sign maker's brackets (USD 5.00) and the bought band brackets (USD 6.00). All prices are indicative until quoted at TRL 4.

Savings worth trying: a cheaper enclosure or sign quote, aiming at the USD 14.00 gap. The site-trial target of USD 750 for a two-sided crossing applies when a trial starts (on hold with TRL 4).

## Decisions made

| Date | Decision | Decided by | Record |
| --- | --- | --- | --- |
| 2026-09-25 | TRL 2 review items D1 to D9: `budget_usd` covers one assembly on an existing pole; PIR gating of the radar; existing poles first and a 114.3 x 3.6 mm post where a new one is needed; FHWA IA-21 baseline; button plus passive detection; LoRa side-to-side link; FieldNode radio core with CrossSafe's own 12 V power; pedestrian pilot light where allowed; no change to the pitch | Amish: "i accept all your recommendations, go with them across all repos." | CRS-DDR-001, CRS-DDR-002 |
| 2026-09-25 | $750 site-trial value-engineering target for a two-sided crossing, to apply when a site trial starts (on hold with TRL 4); `budget_usd` stays $350 | Amish, same instruction | CRS-DDR-002, O2 |
| 2026-09-25 | Ventilated sun shield on the enclosure (E1); anti-rotation bolt on new posts and keyed saddles on existing poles (E2); timed installation trial, on hold with TRL 4 (E3) | Amish, same instruction | CRS-DDR-002 |
| 2026-09-26 | CrossSafe chosen for the first batch of product renders | Amish | REVIEW 2026-09-26 |
| 2026-09-30 | Build plan format approved; open decisions kept in this register, not in the build plan | Amish: "this is the correct build plan ... this is a good quality document format. Extend this across all the other repos" | This register; CRS-BLD-001 |
| 2026-09-30 | Make the design physically buildable while drawing the build plan | Amish: "If you are realising that the design cannot be built as per concept - fix the design assumptions to match and be physically feasible as you draw the illustrations." | CRS-DDR-003 (changes accepted on 2026-10-02, below) |
| 2026-10-02 | Design for construction accepted: the changes P1 to P11 of CRS-DDR-003 and their knock-on changes, as made | Amish: "i approve your recommendations for all 555 open decisions." | CRS-DDR-003, Tables 1 and 2 and A3 |
| 2026-10-02 | Panel mount on existing poles: the prototype is built for free-topped poles of about 114 mm (option c); a side-of-pole panel arm on two more saddles (option b) is designed once the pilot site's poles are known | Amish: "i approve your recommendations for all 555 open decisions." | CRS-DDR-003, A2 |
| 2026-10-02 | Sign rotation on small poles: the existing-pole kit is limited to poles of 76 mm and larger (option b) until a slip-torque test on the keyed saddle confirms the assumed grip; then a third saddle and band at the sign (option a) brings 60 to 75 mm poles back. This changes the earlier recommendation of (a) | Amish: "i approve your recommendations for all 555 open decisions." | CRS-DDR-002, N1 |
| 2026-10-02 | Pilot partner: a United States city traffic engineering department with a Safe Routes to School or Vision Zero programme, since the design follows FHWA IA-21. First candidate to approach: a North Texas city near the team | Amish: "i approve your recommendations for all 555 open decisions." | CRS-DDR-001, O1; CRS-DDR-002 |
| 2026-10-02 | Visors and bezels on the LED heads: added to the model (CRS-CAL-001 v0.6 includes them in the light bar wind area); head modules are bought with visors | Amish: "i approve your recommendations for all 555 open decisions." | `docs/REVIEW.md`, 2026-09-26, item 2 |
| 2026-10-02 | Louvre slots in the sun shield: appearance only until the shield is measured; the shield stays plain sheet | Amish: "i approve your recommendations for all 555 open decisions." | `docs/REVIEW.md`, 2026-09-26, item 3 |
| 2026-10-02 | Sign colour: fluorescent yellow-green in the renders; the sheeting is bought to the local road authority's design | Amish: "i approve your recommendations for all 555 open decisions." | `docs/REVIEW.md`, 2026-09-26, item 4 |
| 2026-10-02 | Small appearance differences in the renders (pilot light housing, saddle flange at the sign, band screw housings) accepted as appearance detail | Amish: "i approve your recommendations for all 555 open decisions." | `docs/REVIEW.md`, 2026-09-26, item 5 |

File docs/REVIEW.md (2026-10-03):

# Review note: CrossSafe

## Session 2026-09-25: /populate to a strong TRL 2

### What was done

- `docs/01-problem.md` (CRS-PRB-001 v0.2): problem with cited figures (WHO, NHTSA, UK DfT, FHWA), users, operating environment, constraints, out of scope, prior work (RRFB, FHWA IA-21, FieldNode), open questions; co-design checklist kept.
- `docs/03-requirements.md` (CRS-REQ-001 v0.2): 15 measurable requirements (R1 to R15) with targets, verification and status at TRL 2, a defined design case and assumptions.
- `docs/02-concept.md` (CRS-PRC-001 v0.2): how it works, numbered components, design choices, first-order numbers (flash time, energy, solar, autonomy, latency, wind load, cost), safety, open questions.
- `cad/src/concept_media.py`: massing model of one beacon assembly (14 numbered parts) with the street, zebra markings and far-side assembly as grey context; a 1.75 m scale figure on the sidewalk.
- `media/`: `hero.png`, `concept-blueprint` (PNG, PDF, SVG), `model.glb` and `viewer.html`, `exploded.png` (BOM callouts), `cutaway.png` (pole-top enclosure) and `flow.png` (daily energy, estimates labeled).
- `bom/bom.csv`: 15 lines with indicative prices, items 1 to 14 numbered to match the exploded view; `bom/bom-notes.md` updated.
- `README.md`: hero image and links line; concept rationale, burning platform, use tables by industry and region, sparked-by text, problem, concept, key components and safety updated.
- `docs/pdf/`: branded PDFs of the three controlled documents.

Media notes: `render_all` was run with `cut=False`; the cutaway and the exploded view were then rendered with the kit's own functions so small parts stay readable. The cutaway shows only the enclosure zone on a short length of post, and the exploded view shortens the post and moves the push button up 700 mm; both images say so.

### Key results (estimates, to be checked at TRL 3)

| Quantity | Estimate | Requirement |
| --- | --- | --- |
| Flash time, 7 m crossing | about 13 s (energy case uses 20 s) | R4 met by design |
| Daily load, 300 activations | about 29.8 Wh (LEDs about 15.4, standby about 14.4) | |
| Solar available to store, 20 W at 2.5 peak sun hours | about 38 Wh/day; break-even about 2.0 h | R7 met |
| Recovery 20 % to full at 5 peak sun hours | about 2.7 days | R7 met |
| Autonomy without sun, 12 Ah battery | about 4.1 days | **R6 not met (5 days)** |
| Side-to-side trigger latency | about 0.1 s | R3 met |
| Post stress, 40 m/s gust, 89 x 4 mm post | about 169 MPa, 72 % of S235 yield | **R9 not met (60 %)** |
| Parts per assembly / per crossing | about $361 / about $722 ($311 per assembly on an existing pole) | **R15 not met** |

Requirements not met or at risk:

- **R6 (autonomy) not met:** about 4.1 days against 5.
- **R9 (structure) not met with the modeled post:** 89 x 4 mm reaches about 72 % of yield; a 76 mm post would yield. A 114.3 x 3.6 mm post (about 47 %) or a 600 mm sign (about 59 %) meets it.
- **R15 (cost) not met:** about $361 per assembly against $350, and a crossing needs two.
- **R2 (visibility) and R5 (detection quality) unverified:** these decide whether the device works at all and need photometry and a site trial.

### Proposed, awaiting Amish

Update 2026-09-25: items 1 to 8 are now "Decided by Amish, 2026-09-25: go with recommendation" (CRS-DDR-002); item 9 has no recommendation and stays "Proposed, awaiting Amish".

1. **Budget (pitch-level).** `budget_usd` is $350, but a working crossing needs two assemblies (about $722). Options: (a) keep $350 and define the prototype as one assembly on an existing pole (about $311), with the second side later; (b) raise `budget_usd` to $750 for a full two-sided prototype; (c) cut cost (one-sided light bar, smaller sign) to bring a pair near $600. Recommendation: (a) for TRL 3 and 4 bench work, then (b) before any site trial. `project.yaml` is unchanged.
2. **Autonomy fix.** Options: gate the radar with a PIR sensor (about 6 days, about $3 more, adds detection logic), an 18 Ah battery (about 6.2 days, about $20 more), or relax R6 to 4 days. Recommendation: PIR gating, with the 18 Ah battery as fallback.
3. **Post and sign size.** Options: 114.3 x 3.6 mm post, a 600 mm sign on the 89 mm post, or existing lighting poles only. Recommendation: design for existing poles first and specify 114.3 mm when a new post is needed.
4. **Reference rules.** Use FHWA IA-21 (US) as the baseline for size and flash pattern, with a configurable pattern for other jurisdictions. Recommendation: yes, and choose the pilot jurisdiction early.
5. **Triggers.** Push button plus passive radar, versus button only. Recommendation: both, with passive detection switchable off where not allowed.
6. **Side-to-side link.** LoRa radio versus a cable under the road. Recommendation: LoRa.
7. **Shared components.** Reuse the FieldNode radio and logging core for the controller; keep CrossSafe's own 12 V power system because the FieldNode power stage is too small; consider CellGuard in place of the drop-in battery's closed BMS later. SwapCell is not proposed (48 V class, far too large). Recommendation: FieldNode radio core yes; CellGuard later.
8. **Pedestrian-facing confirmation light** on the back faces. Recommendation: include, subject to local rules.
9. **Pilot partner and site**, including a road authority willing to review the design.

### Safety concerns

- Road safety: a beacon that fails dark, false-triggers often, or gives pedestrians false confidence can cause harm; fail-safe logic (R12) and road authority approval are essential.
- Structure: the post, sign and panel are a falling hazard in high wind or a vehicle strike; the wind load is the controlling case and is not yet met with the modeled post.
- LiFePO4 battery in a sun-heated box: fusing, BMS, charge temperature limits and enclosure temperature need checking.
- Installation is work at height beside live traffic.

### Problems and notes

- WebSearch was unavailable; every cited figure was checked by fetching the source page. Some facts were left out because they could not be verified (commercial RRFB prices, EU pedestrian share, India's latest national figures, a primary source for sign mounting heights and push-button force limits). The 2.1 m sign height and 22 N button force are proposed targets, not cited rules.
- The WHO India figure (about 10 % of global road deaths) comes from an older WHO country page.
- The legacy `cad/src/model.py` placeholder is untouched (TRL 3 work).
- `project.yaml` pitch and problem remain accurate and are unchanged.

### Recommended next step

Review this note and the media, then decide items 1 to 3. If approved, run `/advance-trl3` to check the energy, photometry, radio link and wind load estimates by calculation and produce the parametric model and drawing sheet.

## Session 2026-09-25: TRL 3

On 2026-09-25 Amish asked for this batch of repos to go through the usual process with the instruction "you know the drill, nothing gets past TRL 3". He has not reviewed this repo's TRL 2 items one by one, so every item that carried a recommendation is adopted as recommended for TRL 3 under Amish's 2026-09-25 instruction, open for his review. This session ran `/advance-trl3` on that basis and stopped at TRL 3.

### What was done

- `docs/decisions/0001-trl2-review-decisions.md` (CRS-DDR-001 v0.1, status proposed): nine items adopted as recommended for TRL 3, open for Amish's review (D1 to D9), and two left open (O1, O2).
- `docs/04-calcs/01-sizing.md` (CRS-CAL-001 v0.1) and `docs/04-calcs/sizing.py`: flash timing, energy budget, autonomy and sensitivity, harvest and recovery, enclosure heat and charging window, radio time on air, latency, link budget and duty cycle, photometry screening, heights and installation, wind load on three posts, clamp torsion, footing embedment and cost, with a status for every requirement. The script imports the model, reads the BOM and `project.yaml`, prints every number the note quotes and writes `docs/04-calcs/results.csv`.
- `cad/src/model.py`: parametric build123d model (sign, light bar, four heads, pilot light, button station, radar and PIR on an arm, panel and bracket, enclosure with battery, charger, controller and antenna, seven band clamps, 114.3 mm post and footing), clash check clean. Exports `cad/step/` and `cad/stl/` for `crosssafe-assembly`, `crosssafe-existing-pole`, `sign-and-light-bar` and `pole-top-enclosure`.
- `cad/src/sheets.py` and `cad/drawings/CRS-DWG-001.svg`, `.pdf`, `.png`: general arrangement at Rev P1, 1:50, marked "CONCEPT, NOT FOR FABRICATION" and "PRELIMINARY, NOT FOR FABRICATION". CRS-DWG-001 was free because the concept blueprint is CRS-DWG-010.
- `bom/bom.csv`: 17 lines, all priced with a supplier type. New lines 16 (PIR) and 17 (pilot light); the post line is the 114.3 mm new-post variant, excluded from the existing-pole total. `bom/bom-notes.md` updated.
- `cad/src/concept_media.py` now builds from the model; all of `media/` was re-rendered and every image checked; temporary `media/_views*` folders deleted. The exploded view draws the PIR and pilot light at three times size so they show, and says so.
- CRS-PRB-001, CRS-PRC-001 and CRS-REQ-001 revised to v0.3; `README.md` (TRL badge and line, links to the drawing and calculations, concept numbers, key components, safety) and `project.yaml` (`trl: 3`, `trl_target: 3`, evidence list) updated. PDFs rebuilt in `docs/pdf/`.

### Requirement status (CRS-CAL-001, Table 5)

None not met, 2 at risk, 3 not verifiable at TRL 3, 4 met on paper, 6 met by design.

| ID | Status | Key number |
| --- | --- | --- |
| R8 Environment | **At risk** | Enclosure 9.6 K (clean) to 14.7 K (dusty) above ambient in sun; no charging above 30.3 to 35.4 °C ambient; 64.7 °C inside at 50 °C ambient, above the typical 60 °C LiFePO4 discharge limit |
| R9 Structure | **At risk** | 114.3 x 3.6 mm post at 100 MPa, 42 % of yield (met); sign clamp torsion 175 N·m against 144 N·m of friction at an assumed 1,000 N band tension |
| R2 Visibility | Not verifiable at TRL 3 | About 3,939 cd per head (screening); SAE J595 Class 1 yellow figures not available |
| R5 Detection quality | Not verifiable at TRL 3 | Needs a site trial |
| R10 Mounting | Not verifiable at TRL 3 | Fit met (60 to 114.3 mm); install estimate 120 min, exactly the 2 h limit |
| R3, R6, R7, R15 | Met on paper | 48 ms (244 ms with retries); 7.7 days (5.4 at -20 °C); break-even 1.05 peak sun hours, recovery 2.05 days; $318.00 per assembly, $636.00 per crossing |
| R1, R4, R11 to R14 | Met by design | 12.8 s flash for 7 m; button 1.05 m; enclosure bottom 2.85 m |

Key numbers: daily load 16.0 Wh (TRL 2: 29.8), because IA-21 lights each head 25 % of the time (TRL 2 assumed 35 %) and the PIR gating cuts standby to 187 mW; base moment 3.35 kN·m in a 40 m/s gust; footing 500 mm by 1.8 m in clay (screening); 2.43 kN·m added to a host pole. R6 and R15, not met at TRL 2, are met on paper after D2 and D1.

### Decisions recorded (CRS-DDR-001)

Decided by Amish, 2026-09-25: go with recommendation (previously adopted for TRL 3, open for his review): D1 `budget_usd` covers one assembly on an existing pole (R15 redefined; `budget_usd` unchanged at $350); D2 PIR gating of the radar, 18 Ah battery as fallback only; D3 existing poles first, 114.3 x 3.6 mm where a new post is needed; D4 IA-21 baseline, configurable pattern; D5 button plus passive detection, switchable off; D6 LoRa side-to-side link; D7 FieldNode radio core, own 12 V power, CellGuard later, SwapCell not used; D8 pedestrian pilot light where allowed; D9 no change to pitch or problem.

### Still awaiting Amish

Update 2026-09-25: items 2 to 4 and the timed-trial suggestion are now "Decided by Amish, 2026-09-25: go with recommendation" (CRS-DDR-002); item 1 stays "Proposed, awaiting Amish".

1. **O1, pilot partner, site and jurisdiction**, including a road authority. No preference stated.
2. **O2, site-trial budget.** Recommended at TRL 2: raise `budget_usd` to $750 before any site trial. Not applied. Against $750 a crossing is $114.00 under on existing poles and $26.00 over with new posts ($776.00).
3. **New, enclosure heat (R8).** Options: (a) a ventilated white sun shield, about $8 (rise 3.9 K; charging to 41.1 °C ambient); (b) move the enclosure under the panel's shadow; (c) accept the loss of harvest on hot days. Recommendation: (a), with (b) considered when the bracket is detailed. Not applied.
4. **New, sign clamp slip (R9).** Options: an anti-rotation bolt or tab through the sign saddle, or a specified higher band tension. Recommendation: an anti-rotation bolt on new posts and a keyed saddle on existing poles, with band tension measured later. Not applied.

Suggestion only, not in the repo: a timed trial of the 2 h installation would settle R10 early.

### Cross-repo consistency

- FieldNode (FND-DDR-001) adopted an STM32WL-class module and LoRaWAN, and "LoRa point-to-point not used" for FieldNode itself. CrossSafe reuses the same module and logging design but runs the side-to-side link in LoRa point-to-point mode (D6), which the module supports. This is a firmware mode difference, not a hardware conflict; noted here, FieldNode not edited. CrossSafe does not use the FieldNode power stage or its $126.00 core cost.
- CellGuard's review says CrossSafe does not use CellGuard at this stage; consistent with D7. No other shared component (MotionCore, ThermaCart, TwinKit, CalRig) is used.

### Safety concerns

- Road safety: a beacon that fails dark, false-triggers or gives pedestrians false confidence can cause harm. Photometry (R2) and detection (R5) are unproven, and road authority approval is essential.
- Heat: in hot sun the battery may exceed its discharge limit; the 45 °C charge cut-off must never be defeated to recover energy.
- Structure: the sign can rotate on band clamps in a storm at the assumed tension; the host pole of an existing-pole install carries about 2.4 kN·m more, which the owner must check; the footing is a screening size only.
- LiFePO4 battery: 5 A fuse at the terminal, BMS with low-temperature charge protection.
- Installation is work at height beside live traffic.

### Gaps and notes

- Citations: IA-21 was fetched again to confirm the flash sequence (each indication lit 200 ms of 800 ms), SAE J595 Class 1 yellow intensity, night dimming and the permitted pilot light; these are now in the docs. The older WHO India page was fetched and still states "about 10 %"; its date is not shown. SAE J595 itself, commercial RRFB prices and the other facts left out at TRL 2 remain unverified and are still left out. WebSearch was not used.
- Assumptions only tests can settle: LED power and intensity, radar duty under PIR gating, charger self-consumption, band tension and the shield factor (borrowed from WWT-CAL-001).
- Media: the kit's cutaway only cuts near the origin, so, as at TRL 2, the enclosure zone is moved to the origin before cutting; the exploded view shortens the post and moves the button up. Both images say so.
- Existing material beyond TRL 3: `build-log/README.md` (scaffold) is present, untouched and not extended. `electronics/` and `firmware/` are empty. No test, build or firmware material exists.

### Recommended next step

TRL 4 is on hold by Amish's instruction; this repo stops at TRL 3. Amish's review is needed on D1 to D9, O1, O2 and items 3 and 4 above. For the record only, TRL 4 would need: a bench build of one assembly on a pole stub; a lab test report (TST, `environment: lab`) covering LED head power and intensity against SAE J595, standby and energy per activation, radio latency and fault behavior, enclosure temperature in sun with and without a shield, and clamp torsion and band tension; and build log entries. None of this has been started.

## Session 2026-09-25: recommendations accepted

On 2026-09-25 Amish wrote: "i accept all your recommendations, go with them across all repos." Every CrossSafe item with a recommendation is now "Decided by Amish, 2026-09-25: go with recommendation", recorded in `docs/decisions/0002-recommendations-accepted.md` (CRS-DDR-002 v0.1). CRS-DDR-001 is revised to v0.2 with the new status.

### Decisions applied and what changed

- **D1 to D9 (CRS-DDR-001):** status wording only; the design already reflected them.
- **O2, site-trial budget $750:** decided, on hold with TRL 4. The recommendation was staged ($350 for TRL 3 and bench work under D1, $750 before a site trial), so `budget_usd` stays **$350**. A crossing is now $664.00 on existing poles and $810.00 with new posts against $750.
- **E1, enclosure heat (R8):** ventilated white sun shield added (model part 18, BOM line 18, $8.00). Dusty enclosure rise 14.7 K before, 3.9 K after; interior at 50 °C ambient 64.7 °C before, 53.9 °C after; charging cut-off ambient 30.3 °C before, 41.1 °C after. R8 at risk before, met on paper after.
- **E2, sign clamp slip (R9):** M10 through-bolt on new posts (part 19, BOM line 19, $3.00, variant) and keyed saddles on existing poles (part 20, BOM line 20, 2 x $3.00). Torsion 175 N·m against 144 N·m of plain-saddle friction before; after, the bolt runs at 12 % of bearing and keyed saddles resist 287 N·m on 114.3 mm and 151 N·m on 60 mm poles (grip friction 0.4 assumed). R9 stays at risk, now only for poles under about 70 mm.
- **E3, timed installation trial:** decided, on hold with TRL 4. The estimate stays 120 min with the shield fitted on the ground.
- Knock-on numbers: the shield enlarges the enclosure's wind area, so the base moment rises from 3.35 to 3.43 kN·m and the 114.3 mm post from 42 % to 44 % of yield; embedment needed 1,776 mm (1,800 modeled); host pole moment 2.43 to 2.51 kN·m. Cost per assembly on an existing pole $318.00 before, $332.00 after; with a new post $388.00 before, $405.00 after.
- Files: `cad/src/model.py` (parts 18 to 20; STEP and STL re-exported; clash check clean), `bom/bom.csv` (20 lines) and `bom/bom-notes.md`, `docs/04-calcs/sizing.py` and `01-sizing.md` (CRS-CAL-001 v0.2; checks C3, G6b, G6c), `cad/src/sheets.py` and CRS-DWG-001 at Rev P2, `cad/src/concept_media.py` and all of `media/`, CRS-PRC-001 v0.4, CRS-REQ-001 v0.4, `README.md`, `project.yaml` (evidence list only), PDFs in `docs/pdf/`.
- `README.md`: "What sparked the idea" rewritten around FHWA's termination of IA-11 over the RRFB patents (December 21, 2017) and the reinstatement as IA-21 once the concept was in the public domain (March 20, 2018). All media and PDFs regenerated with the designmolecule.com footer.

### Requirement status (CRS-CAL-001 v0.2, Table 5)

None not met, 1 at risk, 3 not verifiable at TRL 3, 5 met on paper, 6 met by design.

| ID | Status | Key number |
| --- | --- | --- |
| R9 Structure | **At risk** (poles under about 70 mm) | Post 44 % of yield; bolt 12 % of bearing; keyed saddles hold from about 70 mm |
| R2 Visibility | Not verifiable at TRL 3 | About 3,939 cd per head (screening) |
| R5 Detection quality | Not verifiable at TRL 3 | Needs a site trial |
| R10 Mounting | Not verifiable at TRL 3 | Install estimate 120 min, at the 2 h limit |
| R3, R6, R7, R8, R15 | Met on paper | 48 ms; 7.7 days; break-even 1.05 h; 53.9 °C inside at 50 °C ambient; $332.00 per assembly, $664.00 per crossing |
| R1, R4, R11 to R14 | Met by design | 12.8 s flash for 7 m; button 1.05 m; enclosure bottom 2.85 m |

### Still awaiting Amish

1. **O1, pilot partner, site and jurisdiction.** No recommendation; no preference stated.
2. **N1 (new), sign rotation on poles under about 70 mm.** Options: (a) a third band at the sign on poles under 76 mm; (b) limit the existing-pole range to 76 mm and up; (c) a through-bolt on existing poles where the owner allows drilling. Recommendation: (a). Not applied.

### Cross-repo actions

- **FieldNode:** note CrossSafe as a user of the FieldNode radio and logging core in LoRa point-to-point mode (D6, D7). No change to FieldNode's hardware is needed. Not edited from here.
- **CellGuard:** later option in place of the drop-in battery's BMS (D7); no action now.

### Safety concerns

- Unchanged from the TRL 3 session, except that the sun shield removes the hot-battery concern on paper (the shield factor is not measured) and sign rotation is now a concern only on small existing poles.
- The through-bolt hole must be drilled before galvanizing; drilling an existing pole needs the owner's consent.

### TRL 4

TRL 4 remains on hold by Amish's instruction. The site-trial budget, the timed installation trial and the measurement of band tension, saddle grip and shielded enclosure temperature are decided but not started. `trl: 3` and `trl_target: 3` are unchanged.

## Session 2026-09-26: product appearance model and photoreal renders

Amish chose CrossSafe for the first batch of product renders on 2026-09-26. This session adds an appearance model for photoreal renders; it does not change the design, the calculations, the drawing or the BOM.

### What was added

- `cad/src/product_model.py`: `product_parts()` (74 parts in the groups shell, internal, accessory and context), `TITLE` and `RENDER_VIEWS` (hero, exploded and detail). It imports `PARAMS` and `derived()` from `cad/src/model.py` and keeps every main dimension, height and interface.
- Finished-product detail: a 750 mm sign with rounded corners, fluorescent yellow-green retroreflective sheeting, a black border and a walking-figure symbol on an aluminium blank, with bracket nuts; a charcoal light bar with a parting line, head visors, bezels, clear lenses and amber LED arrays (the left head on each face lit, as in the wig-wag); a lit pilot light; a radar housing with radome and parting line on a round arm, and a PIR Fresnel dome; stainless band clamps with screw housings and serrated keyed saddles; a push-button station with a stainless piezo button, tactile arrow, lit acknowledgement ring, tone grille and a printed instruction plate with security fasteners; the white sun shield with louvre slots and security fasteners over the IP65 enclosure, glands and membrane vent; the battery, MPPT charger and controller board inside; the antenna; the 20 W panel with frame, cells, busbars and junction box on its bracket; and the M10 anti-rotation bolt.
- Context (not in the BOM): a compact patch of sidewalk, kerb, road and crossing markings with tactile paving, and the shared clay mannequin (1.75 m, stand pose) waiting at the kerb.
- `README.md`: the hero image now points to `media/render-hero.png`, with a link to `media/render-exploded.png`. The render files are produced separately.

### Where the appearance model differs from model.py

1. **Post split for framing only.** The one 3.7 m post is drawn as three touching sections in different render groups (lower section as context, sign zone as shell, top as accessory) so the detail view can frame the lamp head. The embedded length and footing are not drawn. No geometry change. No decision needed.
2. **Head visors and bezels.** Visors 26 mm deep over each LED head and bezels 14 mm larger than the 140 x 62 mm lens are not in model.py; they add a little frontal area and depth to the light bar. Proposed, awaiting Amish. Recommendation: keep visors in the design intent and add them to model.py and the wind area in the next CRS-CAL-001 revision, since they cut sun phantom on the lenses.
3. **Louvre slots in the sun shield.** model.py and the shield estimate in CRS-CAL-001 treat the shield walls as plain sheet. Proposed, awaiting Amish. Recommendation: keep the slots as appearance only until the shield factor is measured, then decide whether to adopt them.
4. **Sign colour.** The model uses fluorescent yellow-green sheeting, common at school crossings. The BOM says "local sign design". Proposed, awaiting Amish. Recommendation: show fluorescent yellow-green in renders and leave the colour to the local road authority.
5. **Small envelope changes.** The pilot light housing is 36 mm across (model.py 30 mm), the sign saddles carry a bracket flange at the sign back, and the band clamp screw housings are turned away from the enclosure and the anti-rotation bolt. Proposed, awaiting Amish. Recommendation: accept as appearance detail; no calculation is affected.

### Status

This is an appearance model only: no tolerances and no fabrication detail. `trl: 3` and `trl_target: 3` are unchanged, and TRL 4 remains on hold.

## Session 2026-09-27: kit 1.5.0 and image quality

- Kit 1.5.0 synced: STANDARDS v1.5 (sections 12 to 15: product renders, storefront images and image quality, public release, authorship and signing), `.kit/cards.py`, `.kit/image_qc.py`, `.kit/release_gate.py`, issue templates, and the `/render-product` and `/release` commands. `CLAUDE.md` now matches `.kit/CLAUDE.md`.
- Every `media/render-*.png` recaptioned from its original render with the new layout: the title, concept label and repository sit in a band above the render and the view note in a band below it, each line wrapped to the image width, so no text overlaps other text or the render or runs off the image. `media/card.png` and `media/social-preview.png` regenerated with the same rules.
- `python .kit/image_qc.py` and `python .kit/release_gate.py` pass. trl stays 3.

## Session 2026-09-30: design for construction and the prototype build plan (kit 1.7.0)

Under Amish's 2026-09-30 approval of the build plan format ("this is the correct build plan ... Extend this across all the other repos") and his instruction to make each design physically buildable, kit 1.7.0 was installed (`.kit/`, `.claude/commands/`, `CLAUDE.md`) and `/build-plan` was carried out.

### What was done

- `cad/src/model.py`: rebuilt as a constructable model of 55 components (56 with the new post) with `build_components()`, `pole_context()` and `checks()`; `python cad/src/model.py --check` runs 101 checks on the existing-pole kit and 103 on the new-post variant (no overlaps, every joint touching, clearances, pole range, R14 heights). All pass.
- `docs/decisions/0003-design-for-construction.md` (CRS-DDR-003, Draft): every change and its reason, made under Amish's 2026-09-30 instruction to make the design physically buildable; open for his review.
- `bom/bom.csv` (23 lines) and `bom/bom-notes.md`; `docs/04-calcs/sizing.py` and `01-sizing.md` (CRS-CAL-001 v0.3); CRS-REQ-001 v0.5; CRS-PRC-001 v0.5; `README.md` (links line, "Building the prototype").
- `cad/src/build_plan_media.py`: overview, making sketches CRS-DWG-101 to 109, 13 joint close-ups, 18 assembly step pictures, two drilling layouts and the wiring diagram, in `docs/05-build-plan/` and `cad/drawings/`.
- `docs/05-build-plan.md` (CRS-BLD-001) and `docs/06-design-decisions.md` (CRS-DEC-001); both in `trl_evidence`; `design_state: constructable` in `project.yaml`.
- CRS-DWG-001 at Rev P4; STEP and STL re-exported; concept media regenerated (`hero`, `concept-blueprint`, `model.glb`, `viewer.html`, `exploded`, `cutaway`, `flow`).

### Design changes made for construction (CRS-DDR-003)

1. Pole clamps: eight identical keyed pole saddles (80 x 40 x 60 mm aluminium, 120° keyed V, band groove, two tapped M8 holes) and 19 x 0.76 mm stainless bands replace the concept's rings, which passed through every bracket.
2. Sign: bolted flat on its two saddles, 63.4 mm nearer the pole than the concept's 92 mm stand-off blocks; the light bar now stands 70 mm proud of the sign's plane, still directly under it.
3. Light bar: folded 2 mm channel with lips, screwed bottom cover with a gland, riveted end caps; heads through 128 x 50 mm windows; bolted to its saddle from inside; 12.6 mm further from the pole.
4. Enclosure: hung by its lug kit on a new 4 mm mounting plate with saddle tabs above and below; internal plate on the box's bosses; modules on stand-offs; battery on the floor under a new bent strap; 27.6 mm further from the pole.
5. Enclosure saddles moved to the plate's tabs so their bolts are above the shield roof and below the box.
6. Sun shield: side flanges screwed to the mounting plate; air gap and open bottom unchanged.
7. Radar: on a new bent 40 x 5 mm arm on its own saddle, PIR underneath; PIR underside 2,515 mm (was 2,520 mm).
8. Panel bracket: welded socket, cap and cheeks with a pivot hole and 20° tilt slot; two angle rails on the panel frame lip.
9. Instruction plate on its own saddle (the eighth).
10. Enclosure glands placed in two rows beside the battery; the vent at the lid end.
11. Anti-rotation bolt (new posts): M10 x 160 through the sign, the upper saddle and the post, in place of one sign bolt.

### Key results

- Requirement status (CRS-CAL-001 v0.3): **R15 over the value-engineering target on paper**: $360.00 per assembly on an existing pole against a $350 target ($10.00 over), and $720.00 per crossing against $700 ($20.00 over) (was $332.00 and $664.00). R9 at risk on poles under about 70 mm (unchanged); R2, R5, R10 not verifiable at TRL 3; R3, R6, R7, R8 met on paper; R1, R4, R11 to R14 met by design.
- Wind: base moment 3,521 N·m (was 3,434), 114.3 mm post at 45 % of yield (was 44 %), embedment 1,791 mm needed (1,800 modelled), 2,601 N·m added to an existing pole.

### Proposed, awaiting Amish

All listed in `docs/06-design-decisions.md`: (1) accept the CRS-DDR-003 changes; (2) panel mount for existing poles the socket does not fit (recommended: a side-of-pole arm, designed for the pilot site); and, carried over, N1 (third saddle and band on poles under 76 mm), O1 (pilot partner and jurisdiction) and the four appearance items of 2026-09-26.

### Stale until regenerated on Amish's Mac

The design changed visibly (sign nearer the pole, saddles and bands, mounting plate, radar arm, panel bracket), so `media/render-hero.png`, `media/render-exploded.png`, `media/render-detail.png`, `media/card.png`, `media/social-preview.png` and the appearance model `cad/src/product_model.py` are stale. They were not regenerated here.

### Safety concerns

- The build plan keeps the battery and its fuse out until safety stops S1 to S4, and stops before the 3.7 m post is stood up (S7) and before any roadside installation (S8).
- The bracket welds and galvanizing need a competent welder; never weld galvanized steel indoors.
- Band tension and keyed saddle grip are still assumptions; they decide whether the sign can turn on small poles.

### Recommended next step

Amish reviews the register, chiefly the CRS-DDR-003 changes (item 1) and the Value engineering section. TRL 4 stays on hold.

## Session 2026-10-02: open decisions decided

On 2026-10-02 Amish approved the recommendations for every open decision: "i approve your recommendations for all 555 open decisions." The 8 open decisions of the design decisions register are now in its Decisions made table, dated 2026-10-02.

CRS-DDR-003 (design for construction) is accepted, with A2 and A3 decided as recommended. Item 3 was decided on a changed recommendation: the existing-pole kit is limited to poles of 76 mm and larger until a slip-torque test confirms the keyed saddle's grip, so R10 is restated. CRS-DDR-002 items O1 and N1 are recorded as decided. Also noted: `bom/bom-notes.md` still says raising `budget_usd` to $375 is proposed, which the value-engineering wording of 2026-10-01 superseded; it was left for the next BOM revision.

### Documents changed

- `docs/06-design-decisions.md` (CRS-DEC-001 v0.3)
- `docs/decisions/0003-design-for-construction.md` (CRS-DDR-003 v0.3)
- `docs/decisions/0002-recommendations-accepted.md` (CRS-DDR-002 v0.2)
- `docs/01-problem.md` (CRS-PRB-001 v0.5)
- `docs/02-concept.md` (CRS-PRC-001 v0.7)
- `docs/03-requirements.md` (CRS-REQ-001 v0.7)
- `docs/04-calcs/01-sizing.md` (CRS-CAL-001 v0.5)
- `bom/bom-notes.md` (not a controlled document)
- `README.md` (not a controlled document)

### Follow-up actions to carry approved decisions into the design

1. Decision 2: Model and drawings: design the side-of-pole panel arm on two more saddles once the pilot site's poles are known (not for the prototype).
2. Decision 3: Calculations: change R10's range in `docs/04-calcs/sizing.py` and `results.csv` to 76 to 114.3 mm for the existing-pole kit, and restate R9's status for that range.
3. Decision 3: Plan a slip-torque test of the keyed saddle and band (TRL 4, on hold) before 60 to 75 mm poles return with a third saddle and band; then add that saddle and band to the model and the BOM as a small-pole variant.
4. Decision 3: BOM: change line 13's description from 60 to 114.3 mm poles to the 76 to 114.3 mm range of the existing-pole kit.
5. Decision 5: Model: add the visors and bezels to the LED heads in `cad/src/model.py`.
6. Decision 5: Calculations: add the visors to the light bar wind area at the next CRS-CAL-001 revision and recheck R9.
7. Decision 5: BOM: state on line 3 that the LED heads are bought with visors.
8. Decision 1: Renders: regenerate the photoreal renders, `media/card.png`, `media/social-preview.png` and the appearance model on Amish's Mac to show the accepted design for construction (items 7 and 8 follow with them).

### Points found in the review

1. R10 claims a fit on existing 60 to 114 mm poles, but the panel socket fits only about 114 mm free-topped poles (item 2) and the sign can slip on poles under about 70 mm (item 3); the 'fit met' status overstates what the prototype does.
2. The saddle grip friction (0.4) and band tension (1,000 N) behind R9 on existing poles are assumptions with no planned test until TRL 4, which is on hold.

No CAD model, BOM quantity or price, calculation result or picture was changed. TRL stays at 3; TRL 4 remains on hold.

## Session 2026-10-02: approved follow-ups carried out

Amish approved on 2026-10-02 that every follow-up action from the open-decision sign-off be carried out. Results for the 8 follow-ups listed above:

1. Decision 2, side-of-pole panel arm: not done, it waits for the pilot site's poles (not for the prototype).
2. Decision 3, R10 range: done. `docs/04-calcs/sizing.py` and `results.csv` now state 76 to 114.3 mm; R9 is restated from At risk to Met on paper for that range (keyed saddles resist 191 N·m on a 76 mm pole against 175 N·m, a 9 % margin, at assumed friction and band tension).
3. Decision 3, slip-torque test and third saddle: not done, TRL 4 work (on hold); the small-pole variant is added to the model and BOM only after the test.
4. Decision 3, BOM line 13: done, now 76 to 114.3 mm.
5. Decision 5, model: done. Bezel frames and hood visors (26 mm deep, 15 mm drip lip) added to the four LED heads in `cad/src/model.py`; constructability checks pass (107 and 109 checks, with new touch and clearance checks); STEP and STL regenerated.
6. Decision 5, calculations: done. The four visors add about 0.0005 m² across the road to the light bar wind area (none along the road); R9 rechecked.
7. Decision 5, BOM line 3: done. Bought with bezels and visors, re-priced from USD 10.00 to USD 11.00 a head (an allowance of USD 1.00 a head, to be quoted at TRL 4).
8. Decision 1, renders: the appearance model (`cad/src/product_model.py`) now takes the visor and bezel sizes from `model.py` and the render scenes are exported to `/home/claude/renders/crosssafe` (hero, exploded, detail). Photoreal renders, `media/card.png` and `media/social-preview.png` are made on Amish's Mac next and are not done here.

Requirement status changes: R9 At risk to Met on paper (76 to 114.3 mm poles). R10 range restated to 76 to 114.3 mm, still Not verifiable at TRL 3. R15 stays over the target.

Cost: Value-engineering target: USD 350. Estimated cost of the constructable design: USD 364.00 (USD 14.00 over the target). A crossing is USD 728.00 against USD 700; with new posts USD 437.00 and USD 874.00. `budget_usd` is unchanged. The BOM has no mass column, so no mass is reported.

Pictures regenerated: general arrangement CRS-DWG-001 (Rev P5), making sketch CRS-DWG-101, build plan overview, joint 1, steps 1, 2, 9 and 10, and the concept media (hero, blueprint, exploded, cutaway, flow, model.glb and viewer). `drawing.py --check-text` reports no hits.

Documents changed: CRS-CAL-001 v0.6, CRS-REQ-001 v0.8, CRS-PRC-001 v0.8, CRS-BLD-001 v0.3, CRS-DEC-001 v0.4, `bom/bom.csv`, `bom/bom-notes.md` (the superseded $375 proposal text is removed), `README.md`.

### Cross-repo actions

None for this repo.

## 2026-10-02: photoreal renders redone on the constructable design

Rendered with Blender Cycles on Amish's Mac from the updated appearance model; captioned with `.kit/photo_caption.py`; `media/card.png` and `media/social-preview.png` regenerated with `.kit/cards.py`. Views: hero, exploded, detail. image_qc passes. Appearance deviations are those logged above as proposed, awaiting Amish.

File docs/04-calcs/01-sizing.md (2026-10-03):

---
doc_id: CRS-CAL-001
title: CrossSafe sizing calculations
project: CrossSafe
doc_type: Calculation
version: "0.6"
status: Draft
date: '2026-10-02'
author: Amish Chadha
license: CERN-OHL-S-2.0
revisions:
- version: "0.1"
  date: '2026-09-25'
  author: Amish Chadha
  change: First issue for TRL 3 (flash timing, energy budget and autonomy, enclosure heat, radio link and latency, photometry screening, heights, wind load, clamps and footing, cost)
- version: "0.2"
  date: '2026-09-25'
  author: Amish Chadha
  change: Recommendations accepted by Amish (DDR-002); sun-shielded heat case, anti-rotation bolt and keyed saddles, shielded enclosure wind area, cost
- version: "0.3"
  date: '2026-09-30'
  author: Amish Chadha
  change: Re-run for the constructable design (CRS-DDR-003); enclosure mounting plate in the wind area, PIR height, BOM of 23 lines; R15 now not met on paper
- version: "0.4"
  date: '2026-10-01'
  author: Amish Chadha
  change: Budget treated as a value-engineering target
- version: "0.5"
  date: '2026-10-02'
  author: Amish Chadha
  change: "N1 recorded as decided on 2026-10-02 (existing-pole kit 76 mm and up until a slip-torque test); text only, no number changed"
- version: "0.6"
  date: '2026-10-02'
  author: Amish Chadha
  change: "Re-run for the approved decisions: R10 range 76 to 114.3 mm and R9 restated (met on paper for that range); visors in the light bar wind area; line 3 re-priced; cost $364.00"
---

# CrossSafe sizing calculations

On paper, CrossSafe meets eleven of its fifteen requirements (five by calculation, six by design), has one over its value-engineering target, and leaves three that only photometry, a site trial or a timed installation can settle. The one over target is cost (R15): the saddles, mounting plate, panel bracket and fixings that make the design buildable (CRS-DDR-003, 2026-09-30) and the bezels and visors on the LED heads take the estimated cost of one assembly $14.00 over its $350 value-engineering target. The fixes Amish accepted on 2026-09-25 (CRS-DDR-001 and CRS-DDR-002) do their job. Gating the radar with a PIR sensor, together with the IA-21 flash sequence (each head lit 25 % of the time, not the 35 % assumed at TRL 2), cuts the daily load from about 29.8 to 16.0 Wh and lifts autonomy from about 4.1 to 7.7 days (R6 met, 5.4 days at -20 °C). The ventilated sun shield cuts the enclosure's rise in full sun from 14.7 to 3.9 K when dusty, so the interior stays at 53.9 °C at 50 °C ambient and charging continues up to 41.1 °C ambient (R8 met on paper). The 114.3 x 3.6 mm post reaches 45 % of yield in a 40 m/s gust (R9 target 60 %). An eccentric gust on the sign twists it with 175 N·m; on new posts an M10 through-bolt carries this at 12 % of its bearing resistance, and on existing poles keyed saddles hold on poles of about 70 mm and larger, so R9 is met on paper for the 76 to 114.3 mm range of the existing-pole kit (it was at risk on 60 mm poles, which the kit no longer covers). The estimated cost of one assembly on an existing pole is $364.00 against the $350 value-engineering target, and of a two-sided crossing on existing poles $728.00 against $700 (R15 over the target by $14.00 and $28.00; cost drivers and savings are in the design decisions register). Every number in this note is printed by `docs/04-calcs/sizing.py`; the tag in brackets, for example [B4], is the line of that script's output that carries it.

> **Safety:** These are first-principles estimates for a paper proof of concept. They do not show that the device is safe to put beside a road. Photometry, detection, the battery in a sun-heated box, clamp preload and the foundation must be checked on hardware and by a qualified engineer, and the device needs road authority approval before any use on a public road. See CRS-PRC-001, Safety.

## Scope and method

The note checks every requirement in CRS-REQ-001 v0.8 against the design in CRS-PRC-001 v0.8 and the parametric model `cad/src/model.py`. The script imports the model's `PARAMS` and `derived()`, so heights, wind areas, the post section and the footing are those of the STEP files and drawing CRS-DWG-001. It also reads `bom/bom.csv` and `budget_usd` in `project.yaml`. Run it from the repo root with `python docs/04-calcs/sizing.py`; it also writes `docs/04-calcs/results.csv`.

The design case is CRS-REQ-001's: a marked crossing on a two-lane road 7 m kerb to kerb, one assembly on each side, 300 activations of 20 s per day, 2.5 peak sun hours in the worst month and -20 to +50 °C ambient. Decisions referred to as D1 to D9 are in CRS-DDR-001; the sun shield and anti-rotation detail (E1, E2) are in CRS-DDR-002.

## Assumptions

*Table 1. Main assumptions.*

| Area | Assumption | Basis |
| --- | --- | --- |
| Flash pattern | 800 ms sequence, 75 per minute; each indication lit 4 x 50 ms per sequence | FHWA IA-21, checked on the FHWA page on 2026-09-25 |
| LED heads | 6 W per lit head in daytime; drivers 91 % efficient; no credit taken for night dimming | As CRS-PRC-001 v0.2; to be measured |
| Pilot light | 0.3 W, steady while flashing | Assumed |
| Standby | STM32WL-class radio in continuous LoRa receive 5.5 mA and controller plus PIR 0.1 mA, both at 3.3 V through an 80 % converter; 1 mA at 12.8 V for LED drivers off, fault indicator and BMS; charger self-consumption 4 mA at 12.8 V; radar 0.4 W when on | Typical class figures, assumed; the charger figure is written into BOM line 10 |
| Radar gating | The PIR keeps the radar on 25 % of the day at a busy site | Assumed; sensitivity at 50 % and ungated |
| Solar | 20 W panel; 2.5 peak sun hours worst month, 5 in a good month; panel heat and dust 0.85, MPPT 0.94, cell charge 0.95 | As CRS-PRC-001 v0.2, now split into factors |
| Battery | 12.8 V 12 Ah LiFePO4, 80 % usable; 70 % capacity at -20 °C; 80 % at end of life; charge 0 to 45 °C; discharge to about 60 °C | Typical LiFePO4 data |
| Heat | Clear-sky beam 900 W/m², diffuse 10 % of beam, sun at 70° elevation on the worst azimuth; combined convection and radiation 10 W/m²K; absorptance 0.45 clean light grey, 0.70 dusty; a ventilated shield passes 25 % of the solar gain; no credit for panel shade | Handbook ranges; the shield factor matches WWT-CAL-001 and is not measured |
| Radio | 8-byte packet, SF7, 125 kHz, coding rate 4/5, 8-symbol preamble, explicit header; +14 dBm; 2 dBi antennas; 1 dB cable each end; 25 dB allowance for a bus between the assemblies; -123 dBm sensitivity; up to 2 retries; 868 MHz band with 1 % duty cycle | LoRa time-on-air formula; screening values |
| Photometry | Amber LED 50 lm/W; optic 80 %; beam 20° wide by 10° high | Assumed, for screening only |
| Wind | 40 m/s gust; air 1.225 kg/m³; drag coefficient 1.2 on every part including the post; S235 post, yield 235 MPa | As CRS-REQ-001; not a code check |
| Clamps | Band tension 1,000 N; friction 0.2; torsion from a quarter-width eccentricity of the sign pressure | Tension assumed, to be measured; eccentricity is a common allowance for uneven gust pressure on signboards |
| Anti-rotation | M10 A4-70 through-bolt, stress area 58 mm², shear resistance 0.6 fub As / 1.25; post wall bearing 2.5 α fu d t / 1.25 with α = 0.5 and fu = 360 MPa; keyed saddle grip friction 0.4 | EN 1993-1-8 forms used as a screening check; the grip friction is assumed, to be measured |
| Footing | Non-constrained pole formula after IBC section 1807.3.2.1; lateral soil bearing 100 psf per ft of depth (clay), not doubled | Screening method; a local geotechnical and structural check governs |

## A. Flash time and pattern (R1, R4)

- **Time.** A 7 m crossing at 0.9 m/s takes 7.8 s; with 5 s added the set time is 12.8 s. The 20 s energy case covers crossings up to 13.5 m [A1].
- **Pattern.** IA-21 lights each indication for 200 ms of every 800 ms sequence, a duty of 25 %, not the 35 % assumed at TRL 2 [A2]. This alone cuts LED energy by 29 %.
- **Geometry.** Lenses of 140 x 62 mm exceed the 127 x 51 mm minimum; the bar bottom is at 2,100 mm and the sign's bottom point at 2,250 mm, so the bar sits directly under the sign as IA-21 allows [A3].

## B. Energy, autonomy and recovery (R6, R7)

- **Loads.** The lights flash 1.67 h a day. Four heads draw 6.59 W on average while flashing, 10.99 Wh a day; the pilot light adds 0.50 Wh and radio transmission 0.001 Wh [B1].
- **Standby.** Logic 23.1 mW, 12 V quiescent 12.8 mW, charger 51.2 mW and the gated radar 100 mW average: 187 mW, or 4.49 Wh a day [B2]. At TRL 2 standby was a lumped 0.6 W, almost half the load.
- **Daily load.** 16.0 Wh a day, against the TRL 2 estimate of 29.8 Wh [B3].
- **Autonomy.** 122.9 Wh usable gives 7.69 days; 5.38 days at -20 °C and 6.15 days at end of life. The 18 Ah fallback (not adopted) would give 11.5 days [B4].

*Table 2. Autonomy sensitivity [B5].*

| Case | Standby | Load | Autonomy |
| --- | --- | --- | --- |
| Baseline (PIR-gated radar, 25 % on) | 187 mW | 16.0 Wh/day | 7.69 days |
| Radar on 50 % of the day | 287 mW | 18.4 Wh/day | 6.69 days |
| TRL 2 controller (0.15 W) and a 10 mA charger, gated | 391 mW | 20.9 Wh/day | 5.89 days |
| Radar ungated (no PIR) | 487 mW | 23.2 Wh/day | 5.30 days |
| TRL 2 lumped standby (0.6 W) | 600 mW | 25.9 Wh/day | 4.75 days |

R6 holds in every case except the TRL 2 lump, which the build-up above replaces. The margin rests on a low self-consumption charger and on the PIR gating, both of which are in the BOM.

- **Harvest.** The chain from panel rating to stored energy is 75.9 % efficient. In the worst month the panel stores 38.0 Wh a day, a margin of 22.0 Wh. Break-even is 1.05 peak sun hours. At 5 peak sun hours the surplus is 59.9 Wh a day, which refills the battery from 20 % in 2.05 days [B6].
- **Currents.** Peak charge 1.25 A (0.10 C); average discharge while flashing 0.58 A, and 2.06 A in the 50 ms when all four heads are lit, so the 5 A battery fuse has margin [B7].

## C. Enclosure heat and the charging window (R8)

The 150 x 260 x 300 mm enclosure has 0.324 m² of surface and presents 0.0674 m² to a 70° sun on its worst azimuth [C2].

*Table 3. Enclosure temperature in full sun [C1, C3]. The dusty, shielded case is the design case (CRS-DDR-002).*

| Case | Rise over ambient | Interior at 45 °C | Interior at 50 °C | Charging stops above |
| --- | --- | --- | --- | --- |
| Clean light grey | 9.6 K | 54.6 °C | 59.6 °C | 35.4 °C ambient |
| Dusty | 14.7 K | 59.7 °C | 64.7 °C | 30.3 °C ambient |
| Dusty, with the ventilated shield (design) | 3.9 K | 48.9 °C | 53.9 °C | 41.1 °C ambient |

The BMS and charger stop charging above 45 °C cell temperature as R8 requires. Without a shield the device would lose harvest on hot, clear days above about 30 °C ambient, and at 50 °C ambient a dusty enclosure would reach 64.7 °C, above the typical 60 °C discharge limit of LiFePO4 cells. Amish accepted the recommended fix on 2026-09-25 (CRS-DDR-002): a ventilated white sun shield (part 18, about $8, as in WaterWatch and FieldNode) over the roof and three walls with a 25 mm air gap. With it the rise is 3.9 K, the interior 53.9 °C at 50 °C ambient and charging continues up to 41.1 °C ambient [C3], so R8 is met on paper. The steady-state model ignores the battery's thermal mass, which lags the peak, and gives no credit for shade from the panel 0.78 m above the enclosure top; the shield factor of 0.25 is borrowed from WWT-CAL-001 and not measured. Moving the enclosure under the panel's shadow is to be considered when the bracket is detailed.

## D. Radio link and latency (R3)

- **Time on air.** An 8-byte packet at SF7 and 125 kHz takes 36.1 ms [D1].
- **Latency.** Wake, transmit, receive and switch on the far side take 48 ms; with two retries after lost acknowledgements, 244 ms, inside the 500 ms target [D2].
- **Link budget.** Across 7 m with 25 dB of blockage from a bus, the far side receives -57.1 dBm, 65.9 dB above sensitivity; across 15 m, -63.7 dBm and 59.3 dB [D3]. The link will not limit the design; interference and regional band rules are the real questions.
- **Duty cycle.** Sixty activations in the busiest hour use 4.3 s of airtime per side against 36 s allowed at 1 % [D4].

## E. Photometry screening (R2)

A 6 W amber head with the assumed efficacy and a 20° x 10° beam gives about 3,939 cd on axis: 0.39 lx at a driver's eye at 100 m and 4.38 lx at 30 m. At 100 m the near-lane driver is 2.0° off axis horizontally and 0.6° below the head; at 30 m, 6.7° and 2.0°, both inside the beam [E1]. IA-21 requires the daytime intensity to meet the SAE J595 Class 1 yellow peak luminous intensity; that standard's figures were not available to check, so R2 is not verifiable at TRL 3. The numbers above are the input a photometric check will need, not a result.

## F. Heights, mounting and installation (R10, R11, R14)

- **Heights.** Button center 1,050 mm (R11: 0.9 to 1.1 m); light bar bottom 2,100 mm; enclosure bottom 2,850 mm (R14: 2.8 m), with the shield open at the bottom; radar at 2,600 mm on its arm with the PIR underside at 2,515 mm, so no part or cable of the sensing head is below 2.5 m; overall height 4,031 mm [F1].
- **Poles.** The band clamps and saddles are used on 76 to 114.3 mm poles (decided 2026-10-02); the new-post variant uses 114.3 x 3.6 mm [F2].
- **Installation.** A task estimate for a two-person crew on an existing pole comes to 120 min, exactly the 2 h limit of R10, with the sun shield fitted to the enclosure on the ground and the keyed saddles in place of plain ones [F3]. Only a timed trial can settle it; Amish accepted that trial on 2026-09-25, and it is on hold with TRL 4.

## G. Wind, clamps and footing (R9)

- **Loads.** The dynamic pressure at 40 m/s is 980 Pa. Wind along the road, on the sign face, gives 1,448 N and a base moment of 3,521 N·m (sign 1,839, post 920, shielded enclosure with its mounting plate 449, light bar 238 N·m) [G1]. The shield, and the mounting plate's edges and saddle tabs beside it (CRS-DDR-003), enlarge the enclosure's wind area. The four visors on the LED heads (26 mm deep, with a 15 mm drip lip) lie inside the light bar's outline along the road and add only about 0.0005 m² across it, so no base moment changes by more than 2 N·m. Wind across the road gives 760 N and 1,646 N·m, of which the panel is 416 N·m [G2]. Along the road governs.
- **Post.** *Table 4. Post stress in the 40 m/s gust [G3, G4].*

| Post | Section modulus | Stress | Share of S235 yield | R9 (60 %) |
| --- | --- | --- | --- | --- |
| 76.1 x 3.2 mm | 12,820 mm³ | 251 MPa | 107 % | Yields |
| 88.9 x 4.0 mm | 21,674 mm³ | 153 MPa | 65 % | Not met |
| 88.9 x 4.0 mm with a 600 mm sign | 21,674 mm³ | 122 MPa | 52 % | Met |
| 114.3 x 3.6 mm (decided, D3) | 33,593 mm³ | 105 MPa | 45 % | Met |

The TRL 2 figures (169 MPa and 72 % on the 88.9 mm post) counted the panel face-on in the same gust as the sign; here the two act in different wind directions. The top of the 114.3 mm post deflects about 31 mm (0.8 % of its height) in the gust [G5].

- **Clamps.** A gust whose pressure centre sits a quarter of the sign's width off the pole axis twists the sign clamps with 175 N·m. Two bands at the assumed 1,000 N tension resist about 144 N·m by friction on a 114.3 mm pole and only 75 N·m on a 60 mm pole [G6]. With plain saddles the sign could rotate on its pole in a storm. Amish accepted the recommended anti-rotation detail on 2026-09-25 (CRS-DDR-002):
  - **New posts:** an M10 through-bolt in place of the upper sign saddle's upper sign bolt (part 19), through the sign, the saddle and both post walls. The 175 N·m couple puts 1,535 N on each post wall: 8 % of the bolt's shear resistance and 12 % of the wall's bearing resistance [G6b]. Met.
  - **Existing poles:** keyed saddles with serrated grip faces (part 20). At an assumed grip friction of 0.4 two bands resist 287 N·m on a 114.3 mm pole and 191 N·m on a 76 mm pole, so the sign holds on poles of about 70 mm and larger, which covers the 76 to 114.3 mm range of the existing-pole kit with a 9 % margin on the 76 mm pole [G6c]. The friction and band tension are assumptions that must be measured (TRL 4, on hold). Decided 2026-10-02 (CRS-DDR-002, N1): the existing-pole kit is limited to poles of 76 mm and larger until a slip-torque test confirms the grip, then a third saddle and band brings 60 to 75 mm poles back.
- **Footing.** The resultant of 1,448 N (326 lbf) acts 2.43 m (8.0 ft) above the sidewalk. The non-constrained pole formula gives 1,791 mm of embedment for a 500 mm footing in clay, so the model uses 1,800 mm [G7]. This is a screening size; the local code and soil govern.
- **Existing poles.** An assembly adds 2,601 N·m at the sidewalk to the host pole [G8]. The pole owner must confirm the pole and its foundation can carry it; that check is outside this repo.

## H. Cost (R15)

The BOM has 23 lines, all priced. One assembly on an existing pole costs $364.00 and $437.00 with its own post and anti-rotation bolt, footing concrete excluded [H1]. The design for construction (CRS-DDR-003) added $28.00 and the visors and bezels on the heads $4.00 (line 3, $1.00 a head): eight keyed saddles in place of two ($18.00 more), the enclosure mounting plate ($8.00), the radar arm and battery strap ($3.00), a fuller panel bracket ($6.00 more) and more fixings ($4.00 more), less the sign maker's brackets ($5.00) and the bought band brackets ($6.00). Against the value-engineering target of $350 (`budget_usd`, a hypothetical control target, not a limit) that is $14.00 over on an existing pole and $87.00 over with a new post [H2]. Under D1 the target covers the existing-pole assembly, so R15 is over the target on paper; cost drivers and savings worth trying are in the Value engineering section of `docs/06-design-decisions.md`. A two-sided crossing costs $728.00 on existing poles ($28.00 over R15's $700) and $874.00 with new posts: $22.00 under and $124.00 over the $750 site-trial value-engineering target, which Amish accepted on 2026-09-25 for when a site trial starts (on hold with TRL 4) [H3].

## L. Results against every requirement

*Table 5. Requirement status at TRL 3 (also in `docs/04-calcs/results.csv`).*

| ID | Requirement | Value | Target | Status |
| --- | --- | --- | --- | --- |
| R15 | Affordable | $364.00 per assembly; $728.00 per crossing on existing poles | $350; $700 per crossing | **Over the value-engineering target by $14.00** ($28.00 per crossing) |
| R2 | Visibility | About 3,939 cd per head (screening) | Seen at 100 m in sun; dimmed at night | Not verifiable at TRL 3 |
| R5 | Detection quality | PIR wakes the radar; 1 s dwell | 5 % false, 2 % missed | Not verifiable at TRL 3 |
| R10 | Mounting | Fits 76 to 114.3 mm poles; bar at 2.1 m; about 120 min estimate | Fit; 2.1 m; 2 h | Not verifiable at TRL 3 (install time) |
| R3 | Activation and sync | 48 ms; 244 ms with two retries | 0.5 s or less | Met on paper |
| R6 | Autonomy | 7.7 days (5.4 at -20 °C; 6.2 at end of life) | 5 days or more | Met on paper |
| R7 | Energy balance | Break-even 1.05 peak sun hours; recovery 2.1 days | Neutral at 2.5 h; 3 days or fewer | Met on paper |
| R8 | Environment | 53.9 °C inside at 50 °C ambient (dusty, shielded); charging to 41.1 °C ambient | IP65; -20 to +50 °C; charge 0 to 45 °C | Met on paper |
| R9 | Structure | 45 % of yield on the 114.3 mm post; bolt 12 % of bearing; keyed saddles hold on poles of 70 mm and up | 60 % of yield or less; no sign rotation | Met on paper (76 to 114.3 mm poles; friction and band tension assumed) |
| R1 | Light geometry and pattern | 140 x 62 mm lenses; IA-21 pattern; bar under the sign | 127 x 51 mm min.; IA-21 | Met by design |
| R4 | Flash duration | 12.8 s for 7 m; 20 s energy case | L/0.9 + 5 s; 10 to 40 s | Met by design |
| R11 | Accessibility | Button 1.05 m; piezo; tone, tactile arrow, pilot light | 0.9 to 1.1 m; 22 N or less | Met by design |
| R12 | Fail-safe | Timer-limited flashing; local flashing without link; fault log | Never continuous | Met by design |
| R13 | Privacy | Presence and counts only | No images or audio | Met by design |
| R14 | Theft and vandal resistance | Enclosure bottom 2.85 m; lowest sensing part 2.52 m | 2.8 m; no cables below 2.5 m | Met by design |

## Checks against the TRL 2 figures

| Quantity | TRL 2 (CRS-PRC-001 v0.2) | TRL 3 (this note) | Reason |
| --- | --- | --- | --- |
| Flash time, 7 m | About 13 s | 12.8 s | Confirmed |
| LED energy | About 15.4 Wh/day | 10.99 Wh/day | IA-21 duty 25 %, not 35 % |
| Standby | About 14.4 Wh/day | 4.49 Wh/day | PIR gating (D2) and a component build-up |
| Daily load | About 29.8 Wh/day | 16.0 Wh/day | As above, plus the pilot light (D8) |
| Autonomy | About 4.1 days | 7.69 days | As above |
| Break-even | About 2.0 peak sun hours | 1.05 | Lower load |
| Recovery at 5 peak sun hours | About 2.7 days | 2.05 days | Lower load |
| Latency | About 0.1 s | 48 ms, 244 ms with retries | Confirmed |
| Base moment | About 3.7 kN·m | 3.52 kN·m | Panel and sign loads in different wind directions; shielded enclosure and its mounting plate |
| 88.9 x 4 mm post | 169 MPa, 72 % | 153 MPa, 65 % | As above; still not met |
| 114.3 x 3.6 mm post | 110 MPa, 47 % | 105 MPa, 45 % | As above |
| Cost per assembly | $361 own post; $311 existing pole | $437.00; $364.00 | PIR, pilot light, larger post, sun shield, saddles, bolt, parts added for construction (CRS-DDR-003) |

CRS-PRC-001, CRS-REQ-001 and `README.md` have been brought in line with the TRL 3 column.

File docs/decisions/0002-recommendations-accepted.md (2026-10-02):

---
doc_id: CRS-DDR-002
title: CrossSafe recommendations accepted
project: CrossSafe
doc_type: Design decision record
version: "0.2"
status: Draft
date: '2026-10-02'
author: Amish Chadha
license: CERN-OHL-S-2.0
revisions:
- version: "0.1"
  date: '2026-09-25'
  author: Amish Chadha
  change: Recommendations accepted by Amish (DDR-002)
- version: "0.2"
  date: '2026-10-02'
  author: Amish Chadha
  change: "O1 and N1 decided by Amish on 2026-10-02 (N1 on a changed recommendation: 76 mm and up until a slip-torque test)"
---

# 0002: Recommendations accepted

- **Date:** 2026-09-25
- **Status:** accepted. Every item below with a recommendation is "Decided by Amish, 2026-09-25: go with recommendation". Items without a recommendation stay "Proposed, awaiting Amish".

## Context

On 2026-09-25 Amish wrote: "i accept all your recommendations, go with them across all repos." This record lists every CrossSafe item that carried a recommendation in `docs/REVIEW.md` or CRS-DDR-001, the decision that follows, and what changed in the repo. Where a recommendation offered several options, the recommended option is the decision. Work that belongs to TRL 4 or later (building, testing, measuring, trials, purchasing) is decided but on hold, because TRL 4 is on hold by Amish's instruction. The repo stays at TRL 3.

## Options considered

The options for each item are those listed in `docs/REVIEW.md` (sessions 2026-09-25, /populate and TRL 3) and in CRS-DDR-001.

## Decision

*Table 1. Items decided by Amish on 2026-09-25.*

| # | Item | Decision (the recommendation) | What changed in the repo |
| --- | --- | --- | --- |
| D1 | Budget scope (CRS-DDR-001) | `budget_usd` ($350) covers one assembly on an existing pole for TRL 3 and bench work | Status wording only; R15 already redefined at CRS-REQ-001 v0.3. `budget_usd` stays $350 |
| D2 | Autonomy fix | PIR gating of the radar; 18 Ah battery as fallback only | Status wording only; already in the model, BOM and CRS-CAL-001 |
| D3 | Post and sign size | Existing poles first; 114.3 x 3.6 mm post where a new post is needed; 750 mm sign | Status wording only |
| D4 | Reference rules | FHWA IA-21 baseline, pattern configurable | Status wording only; pilot jurisdiction stays open (O1) |
| D5 | Triggers | Button plus passive detection, switchable off | Status wording only |
| D6 | Side-to-side link | LoRa point-to-point | Status wording only |
| D7 | Shared components | FieldNode radio core; own 12 V power; CellGuard later; SwapCell not used | Status wording only; FieldNode consumer note listed under cross-repo actions in `docs/REVIEW.md` |
| D8 | Pedestrian confirmation | Pilot light where local rules allow | Status wording only |
| D9 | Pitch and problem | No change | `project.yaml` pitch and problem unchanged |
| O2 | Site-trial budget | Raise the budget to $750 for a full two-sided prototype before any site trial (the second stage of the TRL 2 budget recommendation) | Decided but on hold: a site trial is TRL 4 or later work. `budget_usd` stays $350 for the current stage under D1. CRS-CAL-001 v0.2 reports a crossing at $664.00 on existing poles ($86.00 under $750) and $810.00 with new posts ($60.00 over) |
| E1 | Enclosure heat (R8) | Option (a): a ventilated white sun shield, about $8; option (b), the enclosure under the panel's shadow, is considered when the bracket is detailed | Part 18 added to `cad/src/model.py` (roof and three walls, 25 mm air gap, open bottom, antenna hole); BOM line 18 ($8.00); CRS-CAL-001 design case is now the dusty, shielded enclosure: rise 3.9 K (was 14.7 K), 53.9 °C inside at 50 °C ambient (was 64.7 °C), charging to 41.1 °C ambient (was 30.3 °C). R8 moves from at risk to met on paper |
| E2 | Sign clamp slip (R9) | An anti-rotation bolt on new posts and a keyed saddle on existing poles, with band tension measured later | Parts 19 (M10 through-bolt, new posts only) and 20 (two keyed sign saddles) added to the model; BOM lines 19 ($3.00, variant) and 20 (2 x $3.00). CRS-CAL-001 section G: the bolt carries 1,535 N per wall, 12 % of bearing resistance; keyed saddles at an assumed grip friction of 0.4 resist 287 N·m on a 114.3 mm pole and 151 N·m on a 60 mm pole against 175 N·m. Band tension and grip friction measurement is TRL 4 work, on hold |
| E3 | Timed installation trial (suggestion, R10) | A timed trial of the 2 h installation | Decided but on hold (TRL 4). The installation estimate stays 120 min with the shield fitted to the enclosure on the ground |

## Items still open

*Table 2. Items without a recommendation, or new, and still "Proposed, awaiting Amish".*

| # | Item | Status |
| --- | --- | --- |
| O1 | Pilot partner, site and jurisdiction, including a road authority. No preference stated | Decided by Amish, 2026-10-02: a United States city traffic engineering department with a Safe Routes to School or Vision Zero programme; first candidate to approach, a North Texas city near the team (CRS-DEC-001) |
| N1 | New from CRS-CAL-001 v0.2: keyed saddles hold only on poles of about 70 mm and larger at the assumed grip friction. Options: (a) a third band at the sign on poles under 76 mm; (b) limit the existing-pole range to 76 mm and up; (c) a through-bolt on existing poles where the owner allows drilling. Recommendation: (a), because it keeps small poles usable at about $5 more on those sites | Decided by Amish, 2026-10-02, on a changed recommendation: (b) for now, the existing-pole kit limited to 76 mm and larger until a slip-torque test on the keyed saddle confirms the assumed grip; then (a) brings 60 to 75 mm poles back (CRS-DEC-001) |

## Consequences

- `project.yaml`: evidence list gains this record; `budget_usd` stays $350; `trl: 3` and `trl_target: 3`.
- CRS-REQ-001 v0.4: R8 target unchanged, status met on paper; R9 names the anti-rotation detail and stays at risk only for poles under about 70 mm; R15 met at $332.00 per assembly and $664.00 per crossing.
- CRS-PRC-001 v0.4: components 18 to 20, updated heat, wind and cost numbers; decisions shown as decided.
- CRS-CAL-001 v0.2: sun-shielded heat case (C3), anti-rotation checks (G6b, G6c), wind area of the shielded enclosure (base moment 3.43 kN·m, post 44 % of yield), cost $332.00 and $405.00 per assembly.
- CRS-DWG-001 Rev P2: shield, keyed saddles and bolt in the model and the notes.
- Media regenerated from the model with the new parts.
- TRL 4 stays on hold. Nothing in this record authorizes building, testing, measuring or purchasing.

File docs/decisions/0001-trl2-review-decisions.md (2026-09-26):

---
doc_id: CRS-DDR-001
title: CrossSafe TRL 2 review decisions
project: CrossSafe
doc_type: Design decision record
version: "0.2"
status: Draft
date: '2026-09-25'
author: Amish Chadha
license: CERN-OHL-S-2.0
revisions:
- version: "0.1"
  date: '2026-09-25'
  author: Amish Chadha
  change: Record the TRL 2 review recommendations adopted for TRL 3 work under Amish's 2026-09-25 instruction, and the items that remain open
- version: "0.2"
  date: '2026-09-25'
  author: Amish Chadha
  change: Recommendations accepted by Amish (DDR-002)
---

# 0001: TRL 2 review decisions

- **Date:** 2026-09-25
- **Status:** accepted. On 2026-09-25 Amish accepted every recommendation ("i accept all your recommendations, go with them across all repos"), so D1 to D9 and O2 are "Decided by Amish, 2026-09-25: go with recommendation" (see CRS-DDR-002). O1 has no recommendation and remains "Proposed, awaiting Amish".

## Context
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

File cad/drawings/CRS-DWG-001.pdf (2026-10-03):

CONCEPT, NOT FOR FABRICATION | CrossSafe · github.com/BoujeeEnjinia1701/crosssafe

FRONT VIEW
Scale 1:100; looking at the front (along +Y)

TOP VIEW
Scale 1:100; looking down (along -Z)

RIGHT VIEW
Scale 1:100; looking at the right side (along -X)

517

1061 5931

PRELIMINARY, NOT FOR FABRICATION

1050 button

SIDEWALK

2250 sign
2100 bar

2850 encl.

4,031 overall

1800 embed
500

KERB AND WAITING ZONE (+Y)

PANEL FACES THE EQUATOR (-Y)

TRAFFIC SIDE (+X)

1,061 (750 sq. sign)

720 bar | ISOMETRIC VIEW Not to scale; seen from the front right and above, about 30 deg elevation
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

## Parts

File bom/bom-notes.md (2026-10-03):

# BOM notes

- Costs are indicative USD parts prices for one beacon assembly at TRL 3. Suppliers are named by type; no vendor is selected.
- Every line is priced. One assembly on an existing pole (all lines except 14 and 19) is $364.00; with its own 114.3 mm post and anti-rotation bolt (lines 14 and 19, marked "Variant only") it is $437.00. `docs/04-calcs/sizing.py` sums the file and prints both totals (CRS-CAL-001, section H).
- Budget: `budget_usd` in `project.yaml` is $350 and, under CRS-DDR-001 D1 (decided by Amish, 2026-09-25), covers one assembly on an existing pole: $14.00 over since the design for construction (CRS-DDR-003) and the head visors, so R15 is over the target on paper. It is a value-engineering target and `budget_usd` is unchanged; the earlier proposal to raise it to $375 was superseded by the value-engineering wording of 2026-10-01. A new-post assembly is $87.00 over.
- A two-sided crossing is $728.00 on existing poles and $874.00 with new posts. Amish accepted the $750 site-trial budget on 2026-09-25 (CRS-DDR-001 O2); it applies when a site trial starts, which is on hold with TRL 4, so `budget_usd` is unchanged.
- Changes at TRL 3: PIR wake sensor (line 16, D2), pedestrian pilot light (line 17, D8), post changed to 114.3 x 3.6 mm with a 1.8 m embedment (line 14, D3), controller specified as the FieldNode STM32WL-class radio core (line 11, D7), charger self-consumption limit added (line 10).
- Changes under CRS-DDR-002 (recommendations accepted by Amish, 2026-09-25): ventilated sun shield (line 18, $8.00), anti-rotation bolt for new posts (line 19, $3.00, variant) and two keyed sign saddles (line 20, $6.00).
- Changes under CRS-DDR-003 (design for construction, 2026-09-30, accepted by Amish on 2026-10-02): eight keyed pole saddles in place of two (line 20, $24.00), bands without brackets (line 13, $9.00), enclosure mounting plate (line 21, $8.00), radar arm (line 22, $2.00), battery strap (line 23, $1.00), a welded panel bracket with rails (line 7, $16.00), glands and fixings (line 15, $16.00), the sign without its maker's brackets (line 1, $40.00), and an M10 x 160 anti-rotation bolt (line 19).
- Item numbers match the callouts in `media/exploded.png`. Item 15 has no callout.
- Installation, footing concrete, traffic management and road authority fees are not included.
- Decisions of 2026-10-02 (CRS-DEC-001): LED heads (line 3) are bought with visors; the sign sheeting (line 1) is bought to the local road authority's design; the existing-pole kit is used on poles of 76 mm and larger until a slip-torque test, so line 13's bands are used on poles of 76 mm and larger until then. Carried out 2026-10-02: line 3 now states the bezels and visors and is re-priced from $10.00 to $11.00 a head (an allowance of $1.00 a head, to be quoted at TRL 4), which adds $4.00 per assembly; line 13 now states the 76 to 114.3 mm range. No quantity changed. The BOM has no mass column, so no mass is reported in this repo.

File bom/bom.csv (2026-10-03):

Item | qty | spec | supplier | unit_cost_usd | make_buy | notes
1 Crossing warning sign | 1 | 750 mm diamond, 3 mm aluminium, retroreflective sheeting, local sign design; four 9 mm holes on the vertical centre line to suit the keyed saddles | Regional traffic sign maker | 40.00 | buy | Indicative price; the 750 mm sign stays (CRS-DDR-001 D3); the maker's brackets are replaced by the keyed saddles (line 20; CRS-DDR-003)
2 Light bar housing | 1 | Folded 2 mm aluminium channel 716 x 70 x 130 mm with inward lips, screwed bottom cover with a cable gland hole, two riveted end caps, four 128 x 50 mm head cut-outs, gasketed; bolts to its saddle | Local sheet metal fabricator | 20.00 | make | Indicative material cost; housing made in three parts (CRS-DDR-003)
3 Amber LED heads | 4 | Amber LED modules, lens 140 x 62 mm (at least 127 x 51 mm lit), about 6 W each at 12 V, narrow beam optic, dimmable; bought with a snap-on bezel frame and a 26 mm moulded hood visor with a drip lip | LED signal module supplier | 11.00 | buy | Indicative price: USD 10.00 for the module plus an allowance of USD 1.00 for the bezel and visor (added 2026-10-02; to be quoted at TRL 4); two per face; photometry against SAE J595 Class 1 yellow unverified (R2)
4 Push-button station | 1 | Vandal-resistant piezo button with acknowledgement tone, tactile arrow and LED; instruction plate 230 x 300 mm | Electronics distributor | 25.00 | buy | Indicative price
5 Presence radar | 1 | 24 GHz presence sensor module in a small weatherproof housing, presence output only, switched by the controller | Electronics distributor | 10.00 | buy | Indicative price; no images or audio; powered only when the PIR sees motion (CRS-DDR-001 D2)
6 Solar panel | 1 | 20 W monocrystalline, 500 x 360 x 25 mm, Vmp about 18 V | Regional solar distributor | 25.00 | buy | Indicative price
7 Panel bracket | 1 | Welded steel post-top bracket: socket tube 139.7 x 4 x 120 mm, cap plate 140 x 140 x 6 mm, two 6 mm cheeks with a pivot hole and a tilt slot (20 to 40 degrees), three welded M10 nuts and security set screws, galvanized or painted; two aluminium angle rails 40 x 40 x 4 x 360 mm | Local fabricator | 16.00 | make | Indicative material cost; socket fits poles of about 114 mm (CRS-DDR-003)
8 Enclosure | 1 | IP65 polycarbonate, 150 x 260 x 300 mm, with an internal mounting plate on four bosses, a four-lug external mounting kit and a membrane vent | Electronics distributor | 22.00 | buy | Indicative price; glands moved to line 15 (CRS-DDR-003)
9 LiFePO4 battery | 1 | 12.8 V 12 Ah (about 154 Wh), internal BMS with low-temperature charge protection | Battery distributor | 45.00 | buy | Indicative price; 18 Ah kept as a fallback only (CRS-DDR-001 D2)
10 MPPT charge controller | 1 | 12 V, 5 A class, LiFePO4 profile, low-temperature charge cut-off, self-consumption 4 mA or less | Solar distributor | 15.00 | buy | Indicative price; low self-consumption is an assumption of CRS-CAL-001
11 Controller and radio board | 1 | STM32WL-class LoRa module (FieldNode radio core, FND-DDR-001 D2) in point-to-point mode, four LED driver channels with night dimming, real-time clock, fault indicator, 12 V to 3.3 V converter | Electronics distributor | 22.00 | buy | Indicative price; reuses the FieldNode radio and logging core design (CRS-DDR-001 D7)
12 Antenna | 1 | Short whip for the LoRa band, bulkhead connector | Electronics distributor | 5.00 | buy | Indicative price
13 Band clamps | 1 | Eight 19 x 0.76 mm stainless steel bands, about 0.6 m each, with buckles, for 76 to 114.3 mm poles (existing-pole kit, decided 2026-10-02) | Hardware supplier | 9.00 | buy | Indicative price; one band at each keyed saddle (line 20); brackets replaced by the saddles (CRS-DDR-003)
14 Post | 1 | 114.3 x 3.6 mm galvanized steel tube, 3.7 m above sidewalk plus 1.8 m embedment in a 500 mm concrete footing (5.5 m cut length), with cap | Local steel stockist | 70.00 | buy | Variant only: new-post sites; excluded from the existing-pole prototype total (CRS-DDR-001 D1 and D3)
15 Wiring and protection | 1 | Outdoor cable, 5 A fuse and fuse block, four M20 and one M16 cable glands, security fasteners (twenty M8 x 16 bolts, M5, M6 and M10 bolts, nyloc nuts), cable cover on existing poles | Local hardware shop | 16.00 | buy | Indicative price; no exploded-view callout; fixings added for construction (CRS-DDR-003)
16 PIR wake sensor | 1 | Low-power passive infrared motion sensor, about 0.1 mA at 3.3 V, weatherproof lens | Electronics distributor | 3.00 | buy | Indicative price; gates the radar (CRS-DDR-001 D2)
17 Pedestrian pilot light | 1 | Small amber LED pilot light, about 0.3 W, on the kerb end of the light bar | LED signal module supplier | 4.00 | buy | Indicative price; subject to local rules (CRS-DDR-001 D8)
18 Sun shield | 1 | Ventilated white sun shield over the enclosure roof and three walls, 1.5 to 2 mm aluminium, 25 mm air gap, open at the bottom, antenna hole, security fasteners | Local sheet metal fabricator | 8.00 | make | Indicative material cost; fixes enclosure heat (R8; CRS-DDR-002)
19 Anti-rotation bolt | 1 | M10 A4 stainless bolt, 160 mm, with nyloc nut and washers, through the sign, the upper sign saddle and the post | Hardware supplier | 3.00 | buy | Variant only: new-post sites (CRS-DDR-002); holes drilled before galvanizing; replaces one sign bolt (CRS-DDR-003)
20 Keyed pole saddles | 8 | Aluminium flat bar 80 x 40 mm, 6082 class, cut 60 long; 120 degree V with serrated faces, 21 mm band groove across the front, two M8 tapped holes; eight identical | Local sheet metal fabricator | 3.00 | make | Indicative material cost; every part on the pole is held by a saddle and band (CRS-DDR-003); grip friction assumed 0.4 until measured
21 Enclosure mounting plate | 1 | Aluminium sheet 4 mm, 350 x 300 mm with a 90 x 90 mm saddle tab above and below, drilled and tapped | Local sheet metal fabricator | 8.00 | make | Indicative material cost; carries the enclosure lugs and the sun shield (CRS-DDR-003)
22 Radar arm | 1 | Aluminium flat bar 40 x 5 mm, 6082 class, about 330 mm, bent to an L | Local metal stockist | 2.00 | make | Indicative material cost; carries the radar and the PIR (CRS-DDR-003)
23 Battery strap | 1 | Aluminium strip 25 x 2 mm, about 180 mm, bent to a Z, two M4 screws | Local metal stockist | 1.00 | make | Indicative material cost; holds the battery on the enclosure floor (CRS-DDR-003)

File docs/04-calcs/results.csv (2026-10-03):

id | requirement | value | target | status
R1 | Light geometry and pattern | 140 x 62 mm lens; 75 per min; bar directly under the sign | 127 x 51 mm min.; IA-21 pattern | Met by design
R2 | Visibility | about 3,939 cd per head (screening) | seen at 100 m in sun; dimmed at night | Not verifiable at TRL 3
R3 | Activation and sync | 48 ms, 244 ms with retries | 0.5 s or less | Met on paper
R4 | Flash duration | 12.8 s for 7 m; energy case 20 s | L/0.9 + 5 s, 10 to 40 s | Met by design
R5 | Detection quality | PIR wakes radar; 1 s dwell | 5 % false, 2 % missed | Not verifiable at TRL 3
R6 | Autonomy | 7.7 days (5.4 at -20 C; 6.2 at end of life) | 5 days or more | Met on paper
R7 | Energy balance | break-even 1.05 PSH; recovery 2.1 days | neutral at 2.5 PSH; 3 days or fewer | Met on paper
R8 | Environment | interior 53.9 C at 50 C (dusty, shielded); no charge above 41.1 C ambient | IP65; -20 to +50 C; charge 0 to 45 C | Met on paper
R9 | Structure | 45 % of yield on 114.3 mm; bolt 12 % of bearing; keyed saddles hold on poles of 70 mm and up | 60 % of yield or less | Met on paper
R10 | Mounting | 76 to 114.3 mm poles; bar at 2.1 m; about 120 min estimate | fit; 2.1 m; 2 h | Not verifiable at TRL 3
R11 | Accessibility | button 1.05 m; piezo; tone, tactile arrow, pilot light | 0.9 to 1.1 m; 22 N or less | Met by design
R12 | Fail-safe | timer-limited flashing; local flashing without link; fault log | never continuous | Met by design
R13 | Privacy | presence and counts only | no images or audio | Met by design
R14 | Theft and vandal resistance | enclosure bottom 2.85 m; lowest arm part 2.52 m | 2.8 m; no cables below 2.5 m | Met by design
R15 | Affordable | $364.00 per assembly; $728.00 per crossing (existing poles) | $350; $700 per crossing | Not met

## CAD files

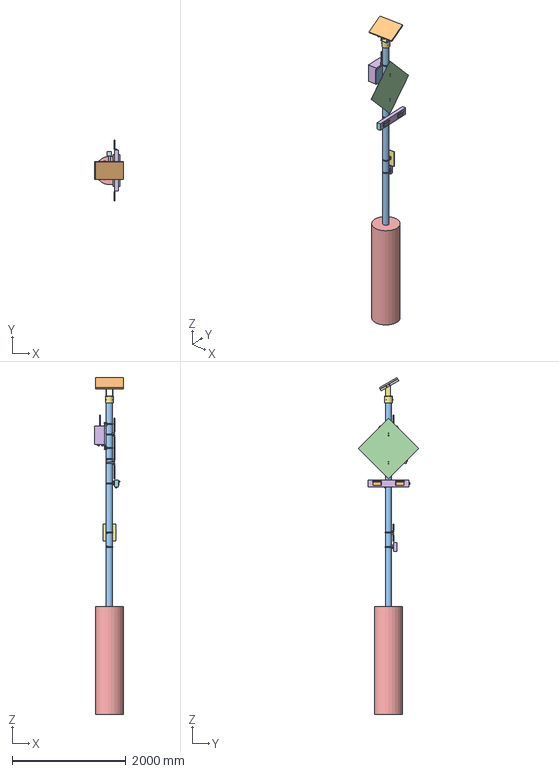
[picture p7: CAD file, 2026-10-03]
cad/step/crosssafe-assembly.step
516.8 x 1060.7 x 5930.8 mm

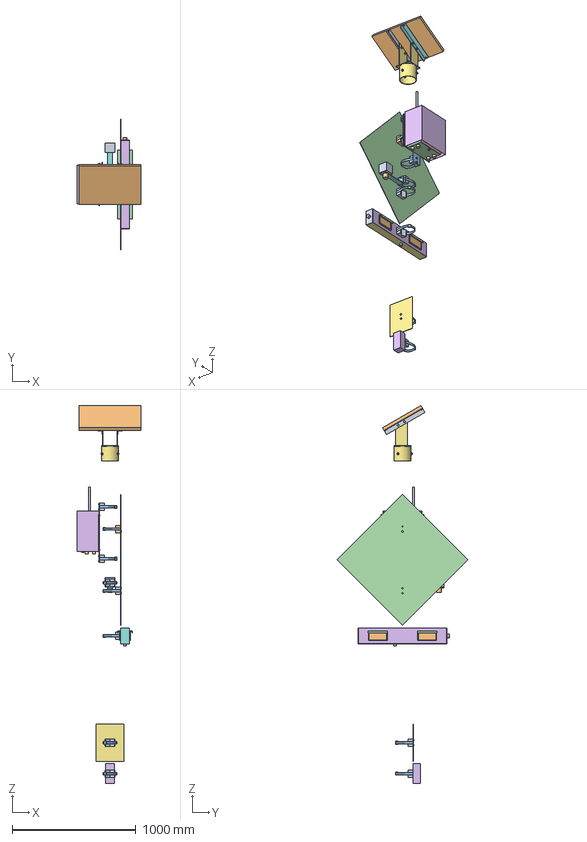
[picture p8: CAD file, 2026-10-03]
cad/step/crosssafe-existing-pole.step
516.8 x 1060.7 x 3060.8 mm

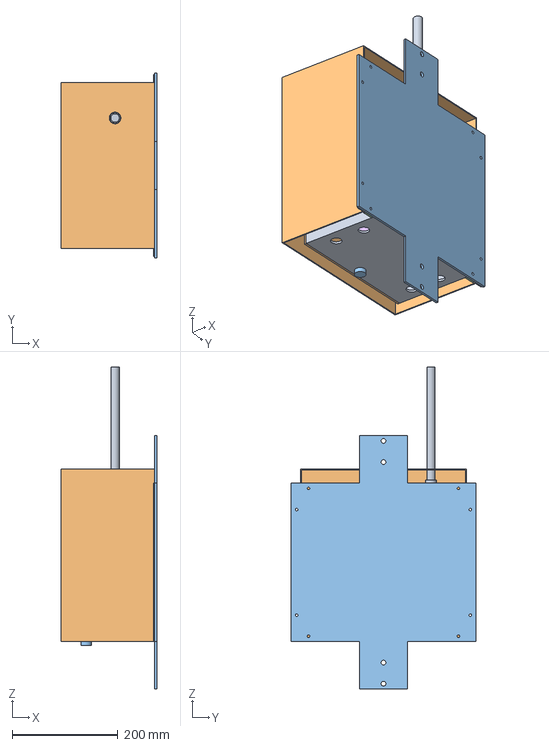
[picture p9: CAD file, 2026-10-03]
cad/step/pole-top-enclosure.step
181.0 x 350.0 x 610.0 mm

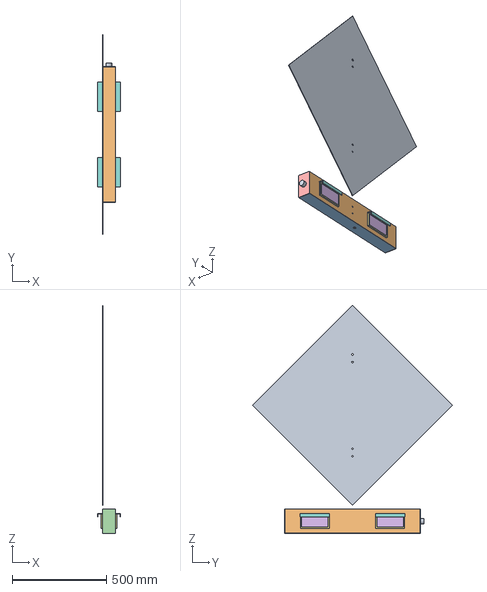
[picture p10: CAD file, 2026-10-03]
cad/step/sign-and-light-bar.step
122.0 x 1060.7 x 1210.7 mm

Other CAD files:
cad/stl/crosssafe-assembly.stl
cad/stl/crosssafe-existing-pole.stl
cad/stl/pole-top-enclosure.stl
cad/stl/sign-and-light-bar.stl

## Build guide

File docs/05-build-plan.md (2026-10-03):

---
doc_id: CRS-BLD-001
title: CrossSafe prototype build plan
project: CrossSafe
doc_type: Build plan
version: "0.3"
status: Draft
date: '2026-10-02'
author: Amish Chadha
license: CERN-OHL-S-2.0
revisions:
  - version: "0.1"
    date: '2026-09-30'
    author: Amish Chadha
    change: First build plan; design made constructable (CRS-DDR-003)
  - version: "0.2"
    date: '2026-10-01'
    author: Amish Chadha
    change: Budget treated as a value-engineering target; cross-references updated
  - version: "0.3"
    date: '2026-10-02'
    author: Amish Chadha
    change: Bezels and visors on the LED heads, cost $364, pole range 76 to 114.3 mm, no open decisions; pictures of joint 1, steps 1, 2, 9 and 10, the overview and CRS-DWG-101 regenerated
---

# CrossSafe prototype build plan

**Plan, not yet built.** How to build the first proof-of-concept prototype, component by component. Building and testing to it is TRL 4 work. Decisions are recorded in the design decisions register ([docs/06-design-decisions.md](06-design-decisions.md)), not here.

## 1. What you are building

Figure 1. Every component, pulled apart and numbered in build order

*Figure 1. Every component pulled apart, numbered in build order and laid out by group.*

The prototype is one CrossSafe assembly, the existing-pole kit, built on a 3.7 m test post of 114.3 x 3.6 mm steel tube that stands in for a site's pole. A crossing warning sign with an amber light bar under it faces the traffic; a push-button station and a radar on a short arm face the kerb; a grey plastic enclosure holding the battery, charger and controller hangs on the back of the pole under a white sun shield; and a solar panel sits on a bracket on the post top. Figure 1 shows the 24 components in the order you make or fit them. Nine are made in a small workshop: the light bar housing, the battery strap, the enclosure mounting plate, two panel rails, eight identical pole saddles, the radar arm, the welded panel bracket and the folded sun shield; the bought enclosure is drilled. Everything else is bought and fitted: the sign, LED heads, pilot light, push-button station and its plate, radar, PIR sensor, panel, battery, charger, controller, glands and stainless bands. The work is sawing, drilling, tapping, filing and folding aluminium bar and sheet, one small steel weldment, drilling a plastic box, and wiring bought modules together with screw terminals. The parts cost about $364 from the bill of materials.

Every part on the pole is held the same way: a saddle with a V in its back sits on the pole, a stainless band runs round the pole and across the saddle's front, and the part bolts to the saddle over the band.

> **Safety:** The prototype holds a 12.8 V lithium iron phosphate battery of about 154 Wh. Keep the battery out of the enclosure and its fuse out of the fuse block until section 6 says otherwise, never charge it below 0 °C or above 45 °C, and never leave a first build charging unattended. The test post weighs about 37 kg and the finished assembly about 30 kg more: build it lying on trestles, and stand it up only as section 6 allows. Sign, sheet and panel edges are sharp: deburr everything and wear gloves. Welding and hot-dip galvanizing are for a trained welder and a galvanizer; never weld galvanized steel indoors.

## 2. What changed to make it buildable

The concept showed what the beacon does; most of its parts were not fixed to anything. Each change below keeps what CrossSafe does, at the same heights, and all of them are recorded in decision record CRS-DDR-003, which Amish accepted on 2 October 2026.

*Table 1. Changes from the concept.*

| Component | The concept had | The buildable design has | Why |
| --- | --- | --- | --- |
| Pole clamps | Rings 8 mm thick drawn through every bracket; each bracket touched the round pole on one line | Eight identical keyed saddles with a V in the back, and a 19 mm stainless band round the pole and across each saddle's front (Figures 15 and 16) | The band pulls the V onto the pole; one saddle fits poles from 76 to 114.3 mm, the range this kit is used on |
| Sign | Standing 92 mm in front of the pole on two solid blocks | Flat on the front of its two saddles, 63 mm nearer the pole, two bolts into each (Figure 18) | The saddle is the stand-off |
| Light bar | A solid box on a block touching the pole on one line; heads stuck on its faces | A folded channel with a screwed bottom cover and riveted end caps; heads through cut-outs; bolted to its saddle from inside (Figures 2, 3 and 17) | A housing that can be made, opened and sealed |
| Enclosure | Held off the pole by a block touching it on one line; battery, charger and controller floating inside | Hung by its lugs on a mounting plate bolted to two saddles; modules on the box's internal plate; battery under a strap (Figures 4 to 11) | Every part has a fixing; the box back stays sealed |
| Enclosure saddles | (Found in checking) bolts that would be hidden behind the box | Saddles on tabs above and below the box (Figure 12) | The enclosure, plate and shield go on and off as one unit |
| Sun shield | No fixing | Side flanges screwed to the mounting plate (Figure 25) | Air gap and open bottom unchanged |
| Radar | On a rod touching the pole on one line | On a bent aluminium arm on its own saddle, PIR underneath (Figure 21) | A part that can be bent and bolted |
| Panel bracket | A sleeve, a block and a tilt plate that touched neither the block nor the panel | A welded socket, cap and two cheeks; two rails on the panel frame, a pivot bolt and a tilt slot (Figures 14, 22 and 23) | Every joint face to face and bolted; tilt 20 to 40° |
| Button and its plate | Touching the pole on one line; the plate with no fixing | Each on its own saddle | The eighth saddle |
| Enclosure bottom | No gland positions; gland nuts under the battery | Four glands in two rows beside the battery; the vent at the lid end (Figures 5 and 6) | Room for every nut |

The parts added for construction and the bezels and visors on the LED heads take the parts cost from $332 to $364.

## 3. Making the components

Make and check each component before the assembly step that needs it. Sizes are in millimetres. "Traffic side" is the side the sign faces; "kerb side" is the side the button and radar face; the enclosure is on the "back" of the pole. Workshop tolerance is 0.5 mm unless a step says otherwise; drawings do not carry tolerances before TRL 4.

### 3.1 Light bar housing

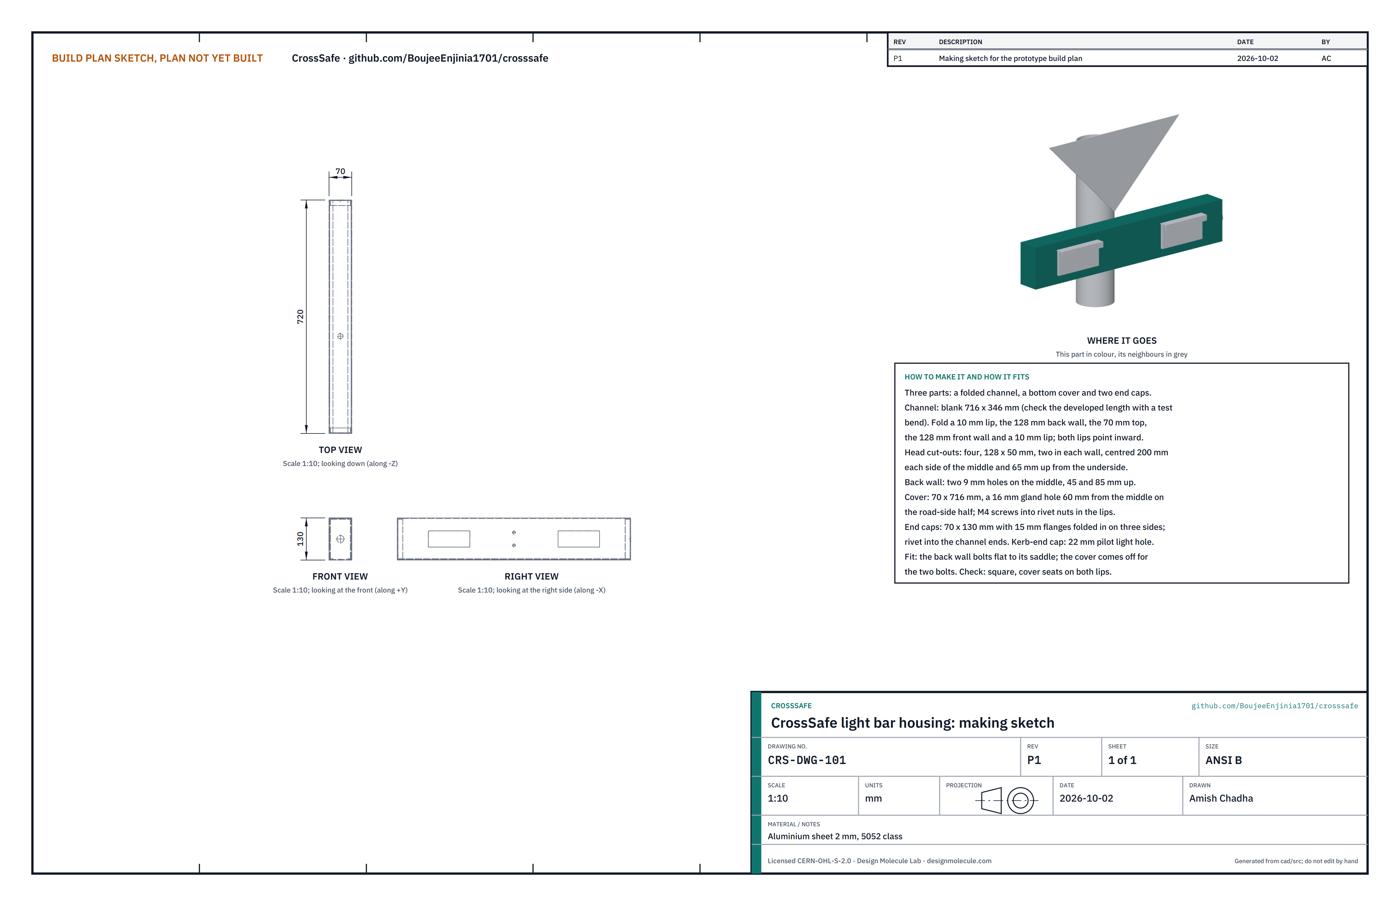
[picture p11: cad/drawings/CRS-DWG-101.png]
Figure 2. Making sketch of the light bar housing


*Figure 2. Light bar housing making sketch (CRS-DWG-101).*

**What it is and what it is made from.** The double-sided box under the sign that carries two amber LED heads on each face, each with a bezel frame and a hood visor, and the pilot light on its kerb end. Aluminium sheet 2 mm, 5052 class, in three parts: a folded channel, a bottom cover and two end caps. Outside size 720 long, 70 deep and 130 tall.

**How to make it.**

1. Cut the channel blank 716 x 346. Mark the fold lines across the 346: 10, 138, 208 and 336 from one edge. Make a test bend in an offcut first and move the lines if your folder's bend allowance differs.
2. Before folding, cut the four head windows, 128 wide and 50 tall: two in each wall, centred 200 each side of the middle of the length and 65 up from what will be the underside of the bar. Drill the corners 6 mm and cut between them with a jigsaw and a fine metal blade; file straight.
3. In the back wall, drill two 9 mm holes on the middle of the length, 45 and 85 up from the underside. These take the bolts to the saddle.
4. Fold the 10 lip, the 128 back wall, the 70 top, the 128 front wall and the other 10 lip, all 90° the same way, so both lips point inward.
5. Fit four M4 rivet nuts in each lip, about 100 apart, to take the cover screws.
6. Cover: cut 70 x 716, drill a 16 hole for the cable gland 60 from the middle toward the road-side end (the end away from the pilot light), and drill clearance holes to match the rivet nuts.
7. End caps: cut two blanks 70 x 130 with a 15 flange on three sides (top, front and back), fold the flanges in, and rivet each cap into the channel ends with two 3.2 rivets per flange. In the kerb-end cap, drill a 22 hole at the centre for the pilot light.

**How it fits the parts next to it.**

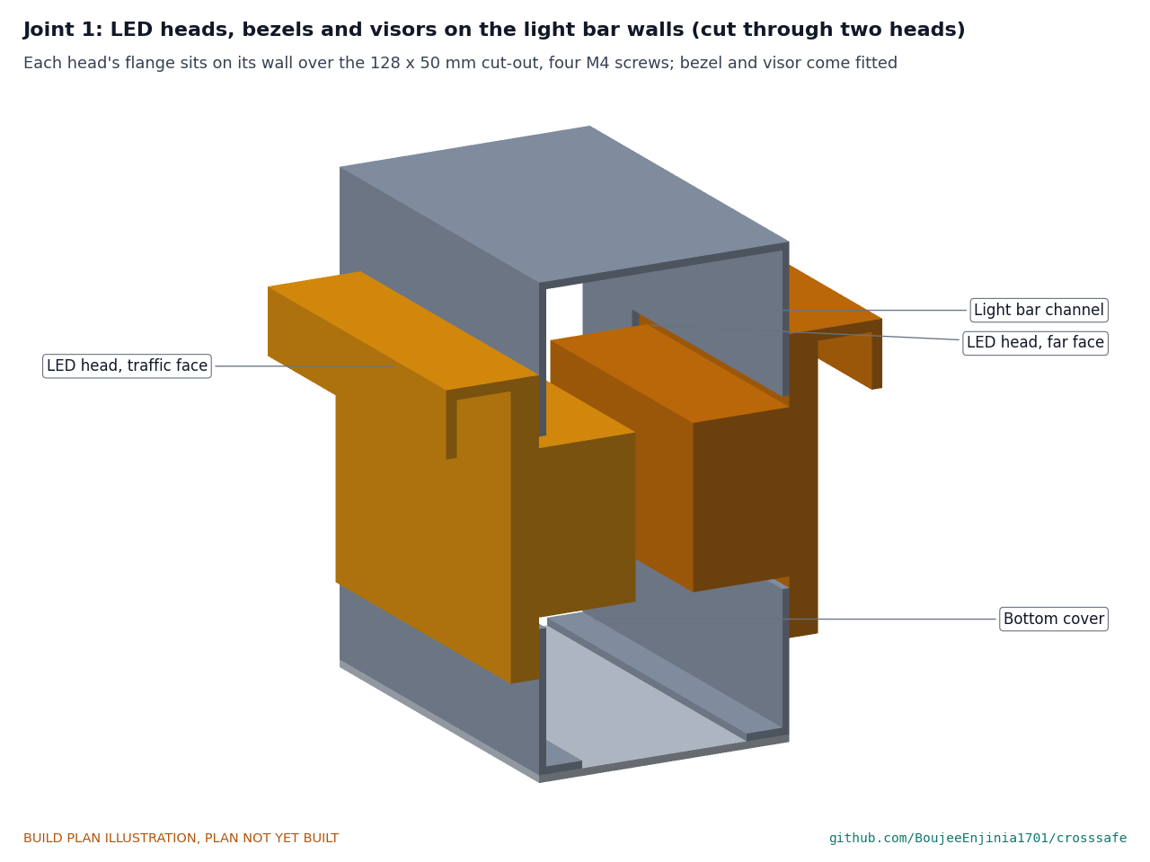
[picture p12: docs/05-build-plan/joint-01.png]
Figure 3. Joint 1: the LED heads, bezels and visors on the light bar walls


*Figure 3. Each head's flange sits on the outside of its wall over the window; its body goes inside, and its bezel and visor are already on it.*

Each head's flange, 140 x 62, sits flat on the outside of its wall and overlaps the 128 x 50 window by 6 all round; four M4 screws through the flange and the wall hold it. The bezel frame is 7 wide round the flange, and the visor sits on top of it and reaches 26 out from the wall, with a 15 high lip at its outer edge that sheds rain from the lens. The two bodies facing each other inside the bar are 16 apart. The back wall sits flat on its saddle (Figure 17); the cover seats on both lips with a foam gasket and comes off to reach the two saddle bolts.

**Check before moving on.** The channel is square along its length within 1 mm; the cover seats on both lips without gaps; each head flange covers its window all round.

### 3.2 Enclosure body, drilled

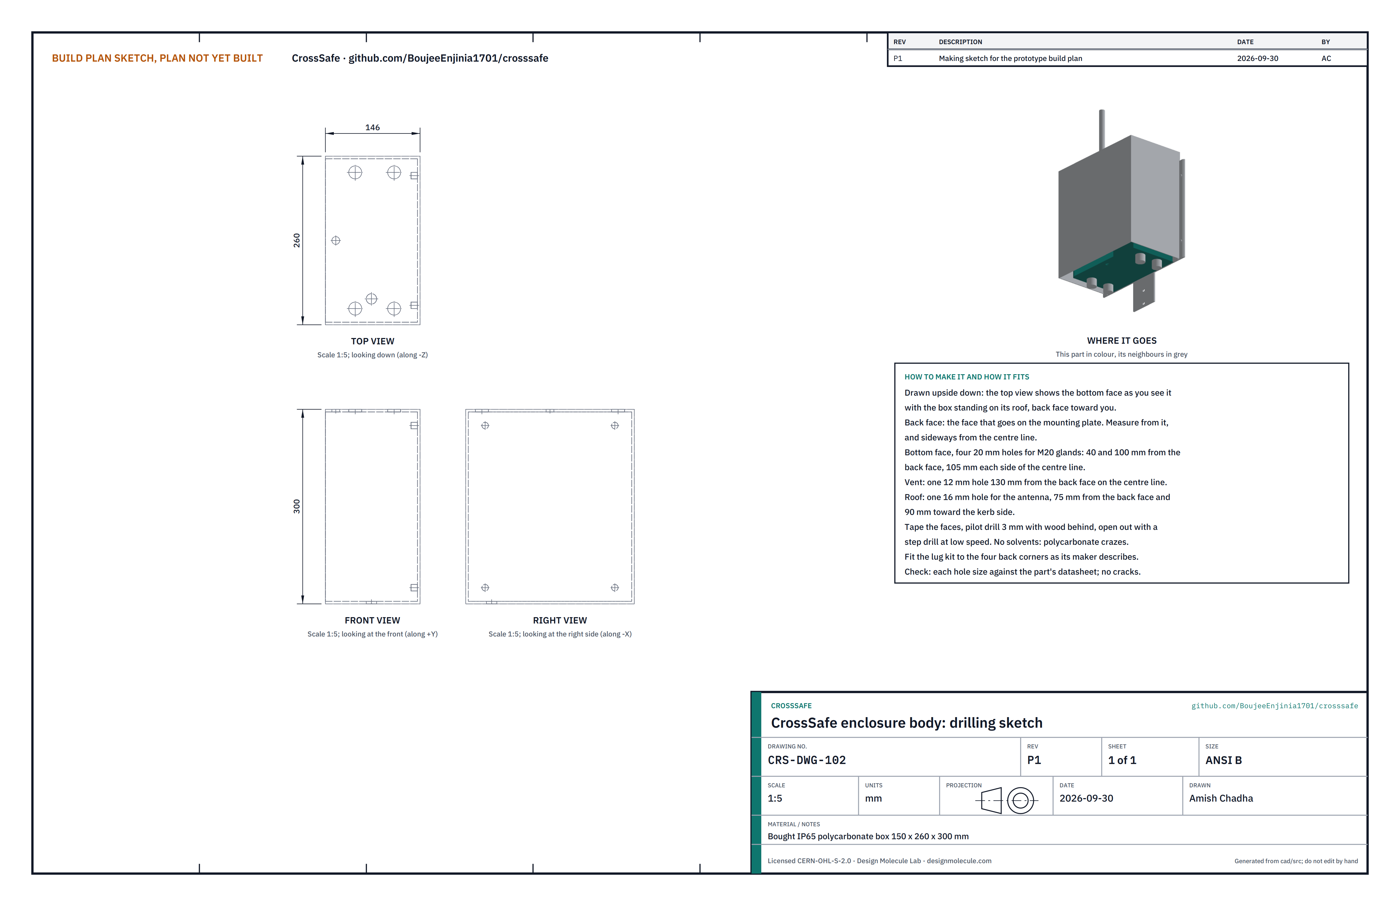
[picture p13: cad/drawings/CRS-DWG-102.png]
Figure 4. Drilling sketch of the enclosure body


*Figure 4. Enclosure drilling sketch (CRS-DWG-102), drawn upside down so the top view shows the bottom face.*

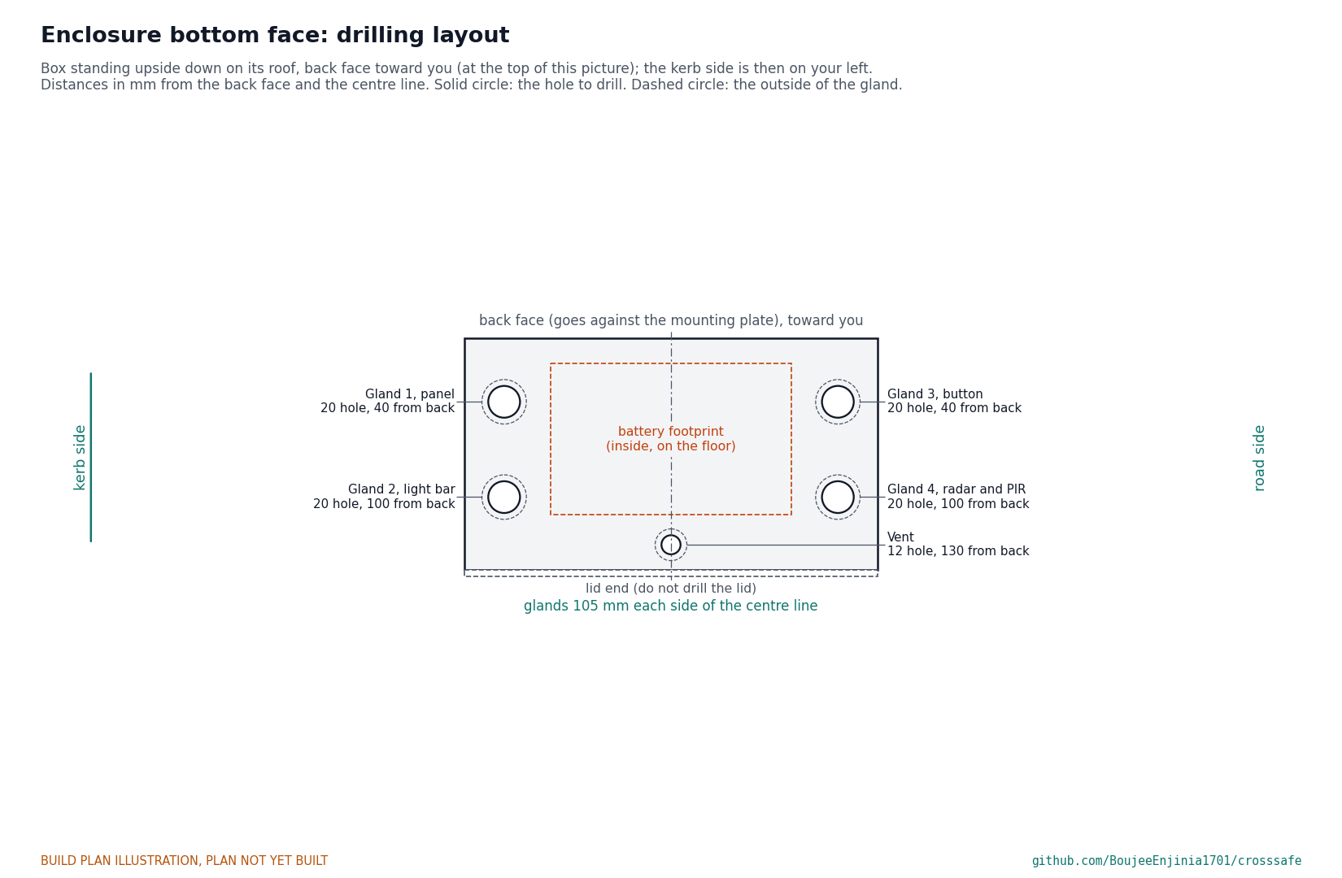
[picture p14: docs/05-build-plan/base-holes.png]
Figure 5. Bottom face drilling layout


*Figure 5. Drilling layout, with the box standing upside down on its roof and its back face toward you.*

**What it is and what it is made from.** A bought grey polycarbonate box, 150 deep, 260 wide and 300 tall, rated IP65, with its lid on the face away from the pole, an internal mounting plate on four bosses inside the back wall, a four-lug mounting kit and a membrane vent. Five holes are drilled in its bottom face and one in its roof.

**How to make it.**

1. Decide the box's kerb side: with the box upright and its back face (the face that goes on the mounting plate) toward you, the kerb side is on your right. Mark it. Stand the box upside down on its roof on a soft cloth, back face toward you; the kerb side is now on your left. Cover the bottom face with masking tape.
2. Mark the holes from Figure 5, measuring from the back face and sideways from the centre line: four 20 holes for the M20 glands, 40 and 100 from the back face and 105 each side of the centre line; one 12 hole for the vent, 130 from the back face on the centre line.
3. Put a block of wood inside under the face. Pilot drill every hole 3 at low speed; do not centre punch hard, since polycarbonate cracks.
4. Open each hole with a step drill, light pressure, low speed. Before the last step, check the size against the gland's and the vent's datasheets.
5. Turn the box over. In the roof, drill a 16 hole for the antenna bulkhead, 75 from the back face and 90 toward the kerb side of the centre line.
6. Deburr inside and out, peel the tape, and clean with water and mild soap only; solvents craze polycarbonate.
7. Fit the four lugs to the box's back corners as the lug kit's maker describes.

**How it fits the parts next to it.**

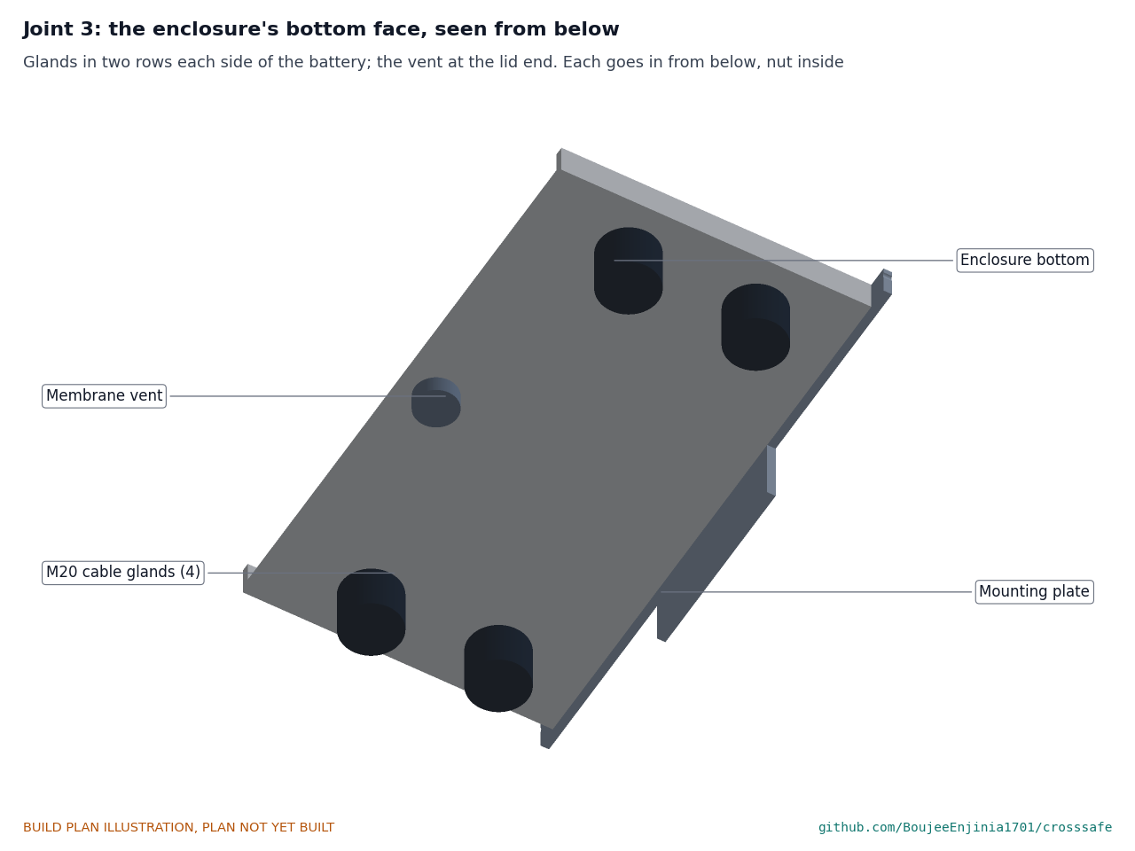
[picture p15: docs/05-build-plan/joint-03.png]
Figure 6. Joint 3: the bottom face from below


*Figure 6. Glands in two rows each side of the battery's place; the vent at the lid end.*

Each gland and the vent go in from outside with the sealing washer outside and the nut inside. The glands sit beside the battery, not under it: every inside nut is at least 5 clear of the battery. The panel lead uses the kerb-side gland nearer the back face, the light bar lead the kerb-side gland nearer the lid, the button lead and the radar lead the two road-side glands.

**Check before moving on.** Each part seats flat on its washer; no crack runs out from any hole under a bright lamp.

### 3.3 Battery strap and internal plate

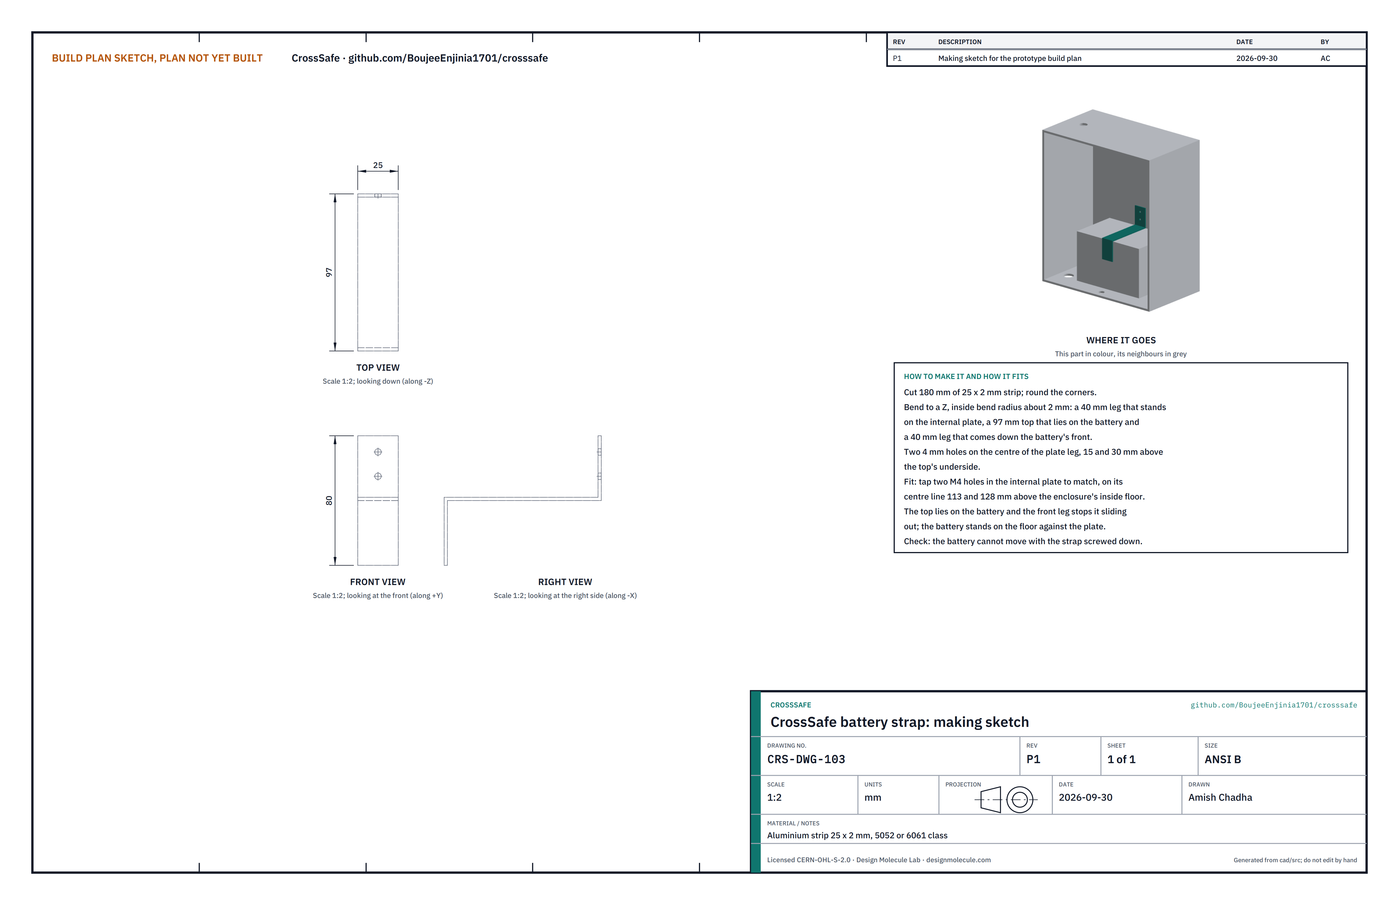
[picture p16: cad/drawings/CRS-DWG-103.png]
Figure 7. Making sketch of the battery strap


*Figure 7. Battery strap making sketch (CRS-DWG-103).*

**What it is and what it is made from.** A Z-shaped strip that holds the battery down on the enclosure floor and against the internal plate; and the box's own internal plate, which carries the charger, the controller and the fuse block and lifts out with them. The strap is aluminium strip 25 x 2, 5052 or 6061 class. The internal plate (220 x 270 x 2) comes with the box.

**How to make it.**

1. Strap: cut 180 of strip and round its corners. Bend it to a Z with an inside radius of about 2: a 40 leg that stands on the internal plate, a 97 top that lies on the battery and a 40 leg that comes down the battery's front.
2. Drill two 4 holes on the centre of the plate leg, 15 and 30 above the underside of the top.
3. Internal plate: tap two M4 holes on its centre line, 113 and 128 above the enclosure's inside floor (measure from where the plate sits on its bosses), for the strap.
4. Lay out the charger, the controller board and the fuse block on the plate's front as Figure 9 shows: charger on the road side at 110 to 170 above the floor, fuse block on the kerb side at the same height, controller board across the middle from 180 to 280 above the floor. Keep the area below 110 clear for the battery.
5. Mark each module's holes through the module, drill 3.2, and fit the modules on M3 screws with 6 nylon stand-offs.
6. Wire the modules as Figure 8 shows.

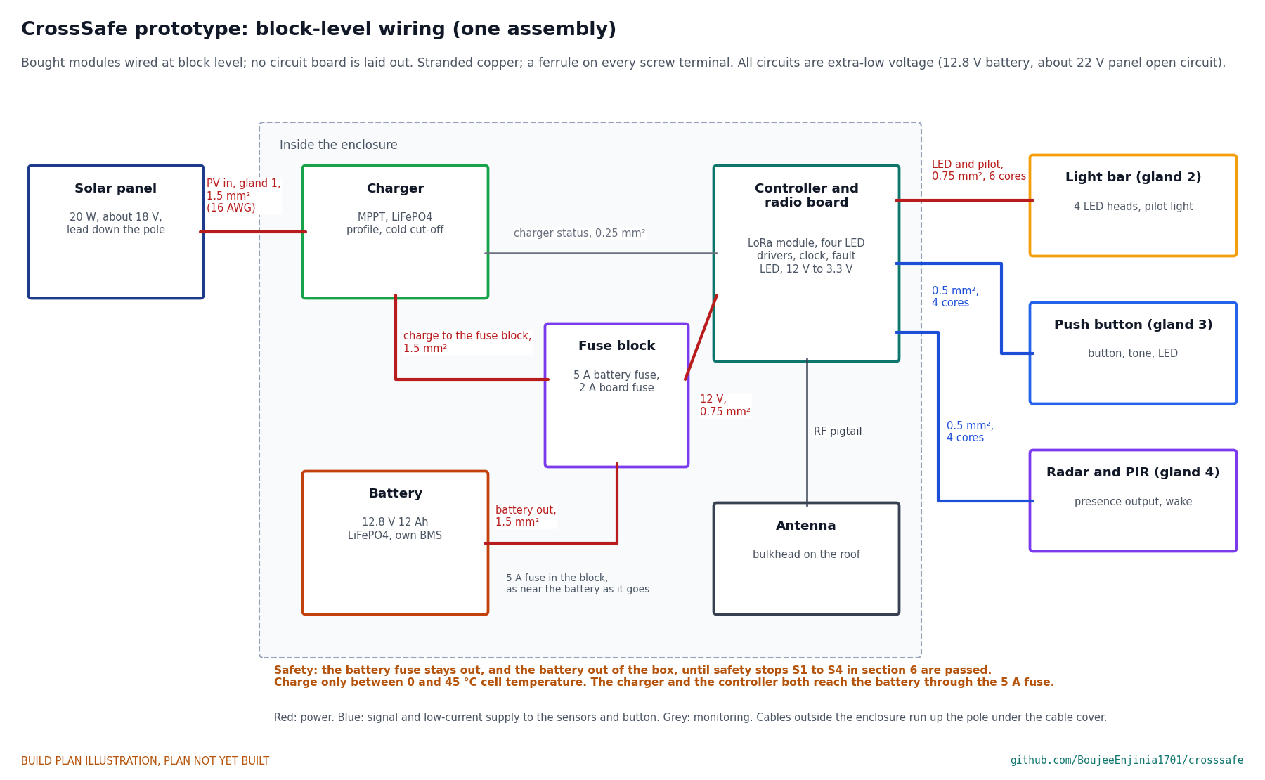
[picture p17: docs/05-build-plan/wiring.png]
Figure 8. Block-level wiring


*Figure 8. Block-level wiring with wire sizes. No circuit board is laid out at this stage; the controller is the FieldNode radio core on its maker's breakout with bought LED driver modules.*

Wire it with stranded copper and a ferrule on every screw terminal: 1.5 mm² (16 AWG) for the panel to the charger, the charger to the fuse block and the battery to the fuse block; 0.75 mm² for the fuse block to the controller and for the six cores to the light bar; 0.5 mm² for the four-core leads to the button and to the radar and PIR; 0.25 mm² for the charger's status lines. The 5 A battery fuse goes in the fuse block, as near the battery as the leads allow, and stays out until section 6 allows it. Leave each outside lead coiled and labelled at its gland until step 16.

**How it fits the parts next to it.**

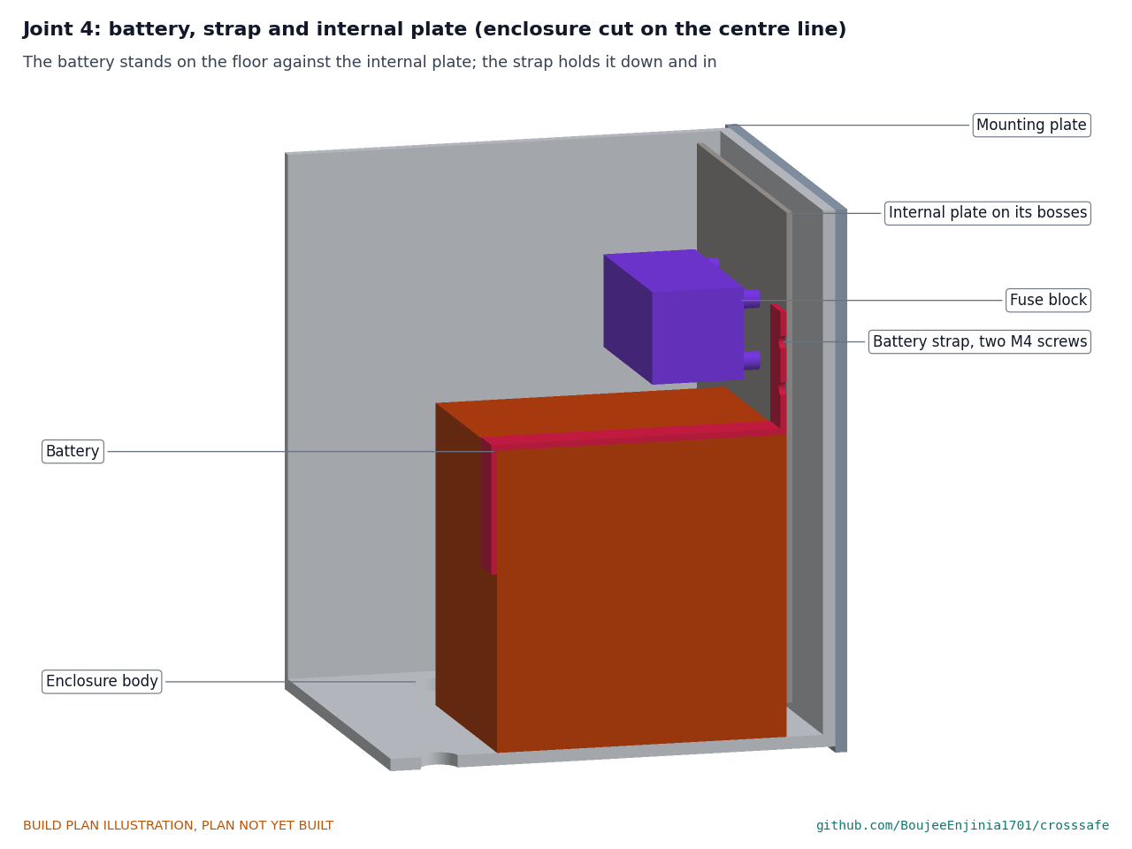
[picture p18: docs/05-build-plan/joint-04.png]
Figure 9. Joint 4: battery, strap and internal plate


*Figure 9. The battery stands on the floor against the internal plate; the strap holds it down and in.*

The internal plate sits on the four moulded bosses inside the back wall, 10 off the wall, held by four M4 screws. The battery (151 wide, 95 deep, 98 tall) stands on the floor with its back against the internal plate, between the two rows of glands. The strap's top lies on the battery and its front leg stops the battery sliding toward the lid; its two M4 screws go into the internal plate.

**Check before moving on.** With the strap screwed down on a dummy block the size of the battery, the block cannot move; every wire is labelled and continues end to end.

### 3.4 Enclosure mounting plate

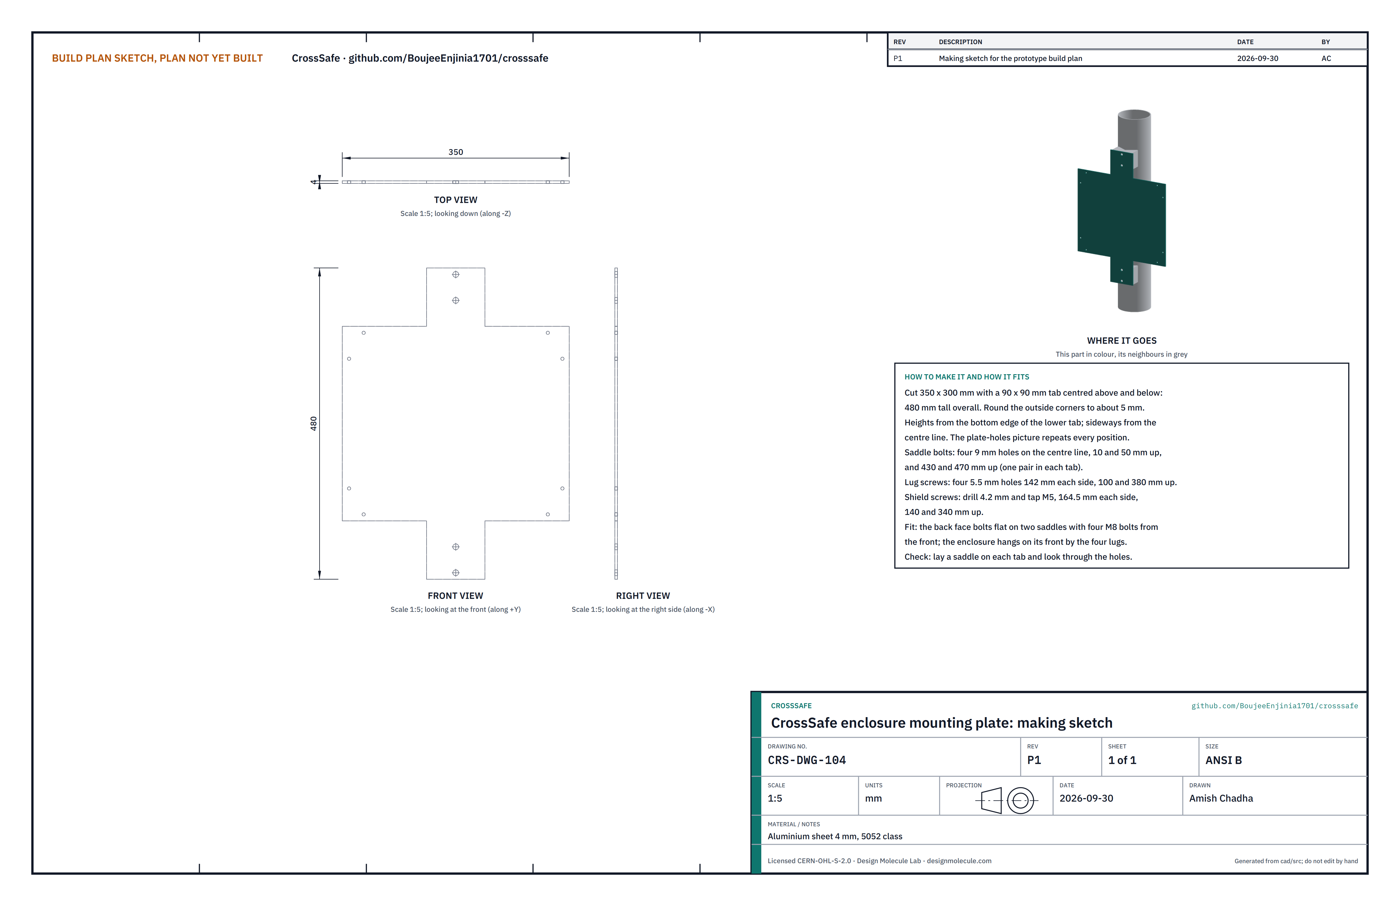
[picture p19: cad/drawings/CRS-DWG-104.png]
Figure 10. Making sketch of the enclosure mounting plate


*Figure 10. Mounting plate making sketch (CRS-DWG-104).*

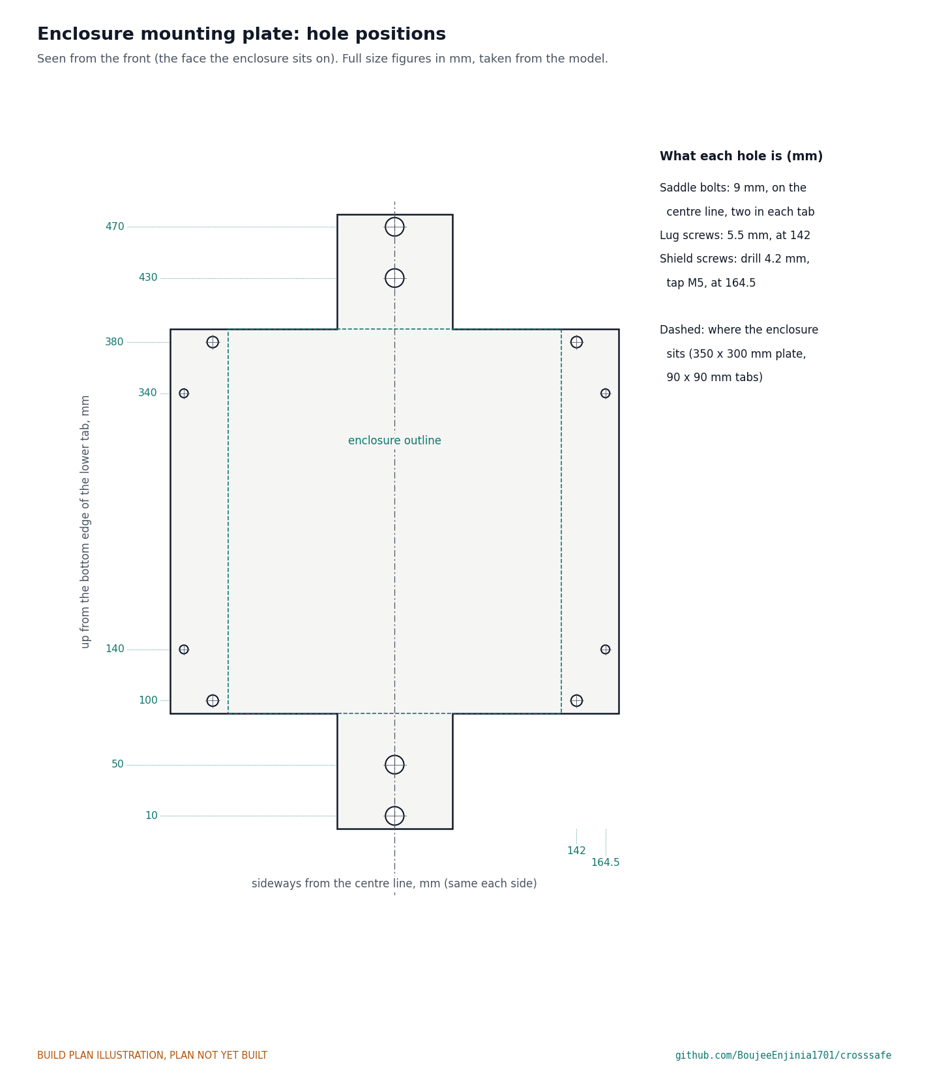
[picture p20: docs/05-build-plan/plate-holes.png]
Figure 10a. Hole positions on the mounting plate


*Figure 10a. Every hole, full size figures, measured up from the bottom edge of the lower tab and sideways from the centre line.*

**What it is and what it is made from.** The flat plate the enclosure and the sun shield hang on; its two tabs bolt to two saddles on the back of the pole. Aluminium sheet 4 mm, 5052 class: 350 wide and 300 tall, with a 90 x 90 tab centred above and below, 480 tall overall.

**How to make it.**

1. Cut the outline and round the outside corners to about 5. File the inside corners of the tabs to a small radius so they cannot start a crack.
2. Scribe a centre line down the length. Mark every hole from Figure 10a: heights up from the bottom edge of the lower tab, sideways from the centre line.
3. Saddle bolts: four 9 holes on the centre line, 10 and 50 up (lower tab) and 430 and 470 up (upper tab).
4. Lug screws: four 5.5 holes, 142 each side, 100 and 380 up.
5. Shield screws: four holes 164.5 each side, 140 and 340 up; drill 4.2 and tap M5.
6. Deburr every hole on both faces.

**How it fits the parts next to it.**

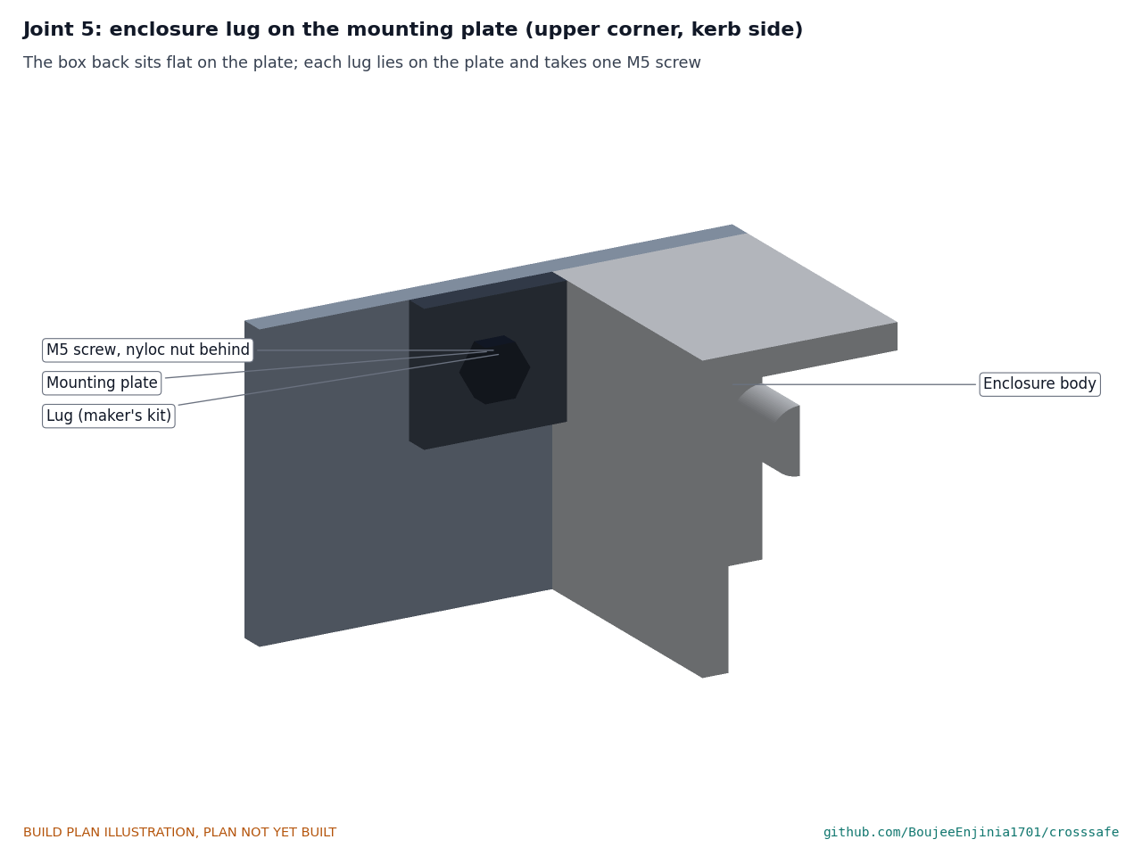
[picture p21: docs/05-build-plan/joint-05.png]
Figure 11. Joint 5: an enclosure lug on the mounting plate


*Figure 11. The box's back sits flat on the plate; each lug lies flat on the plate beside the box and takes one M5 screw, nyloc nut behind.*

The enclosure's back face sits flat on the plate's front between 90 and 390 up. Each lug sits on the plate beside the box and is held by one M5 screw from the front with a nyloc nut behind the plate. The plate's back face sits flat on two saddles, one behind each tab, held by two M8 bolts into each from the front:

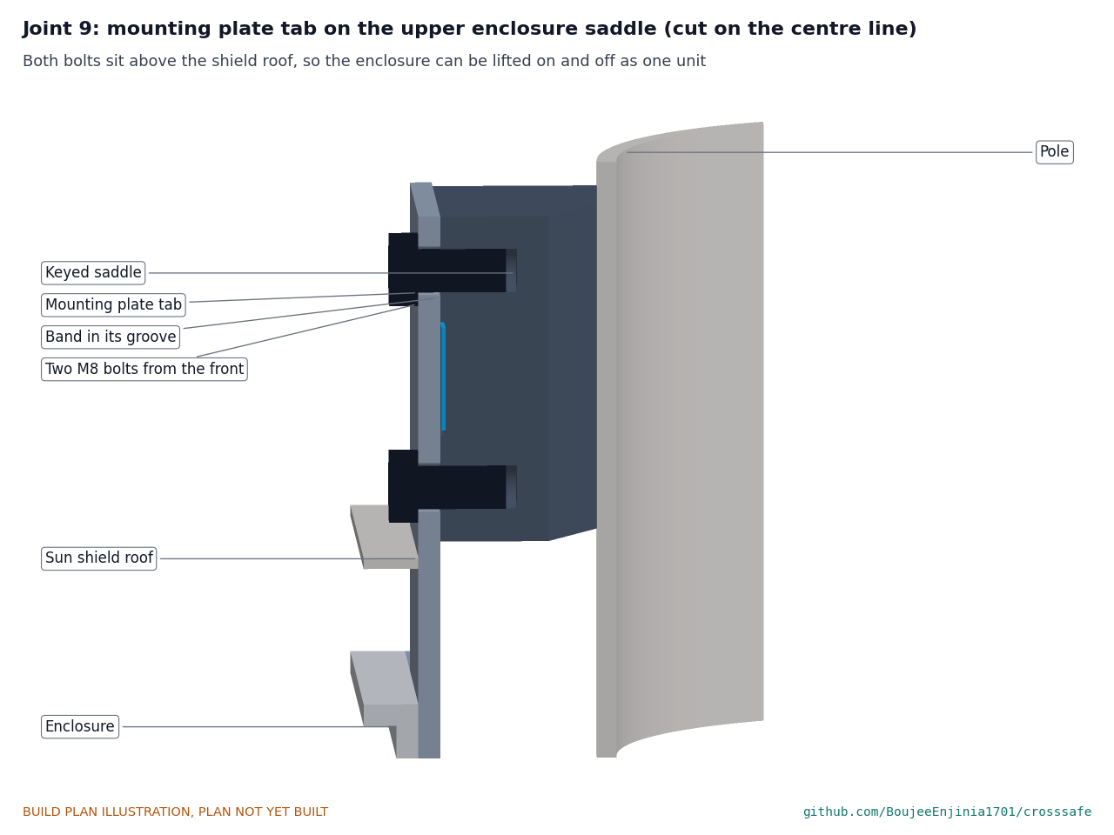
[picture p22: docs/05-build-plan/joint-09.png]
Figure 12. Joint 9: a mounting plate tab on its saddle


*Figure 12. Both bolts of the upper tab sit above the sun shield's roof; both bolts of the lower tab sit below the box.*

**Check before moving on.** Lay a saddle on each tab and look through the holes; lay the box with its lugs on the plate and check all four lug holes line up.

### 3.5 Panel rails (make 2: a left and a right)

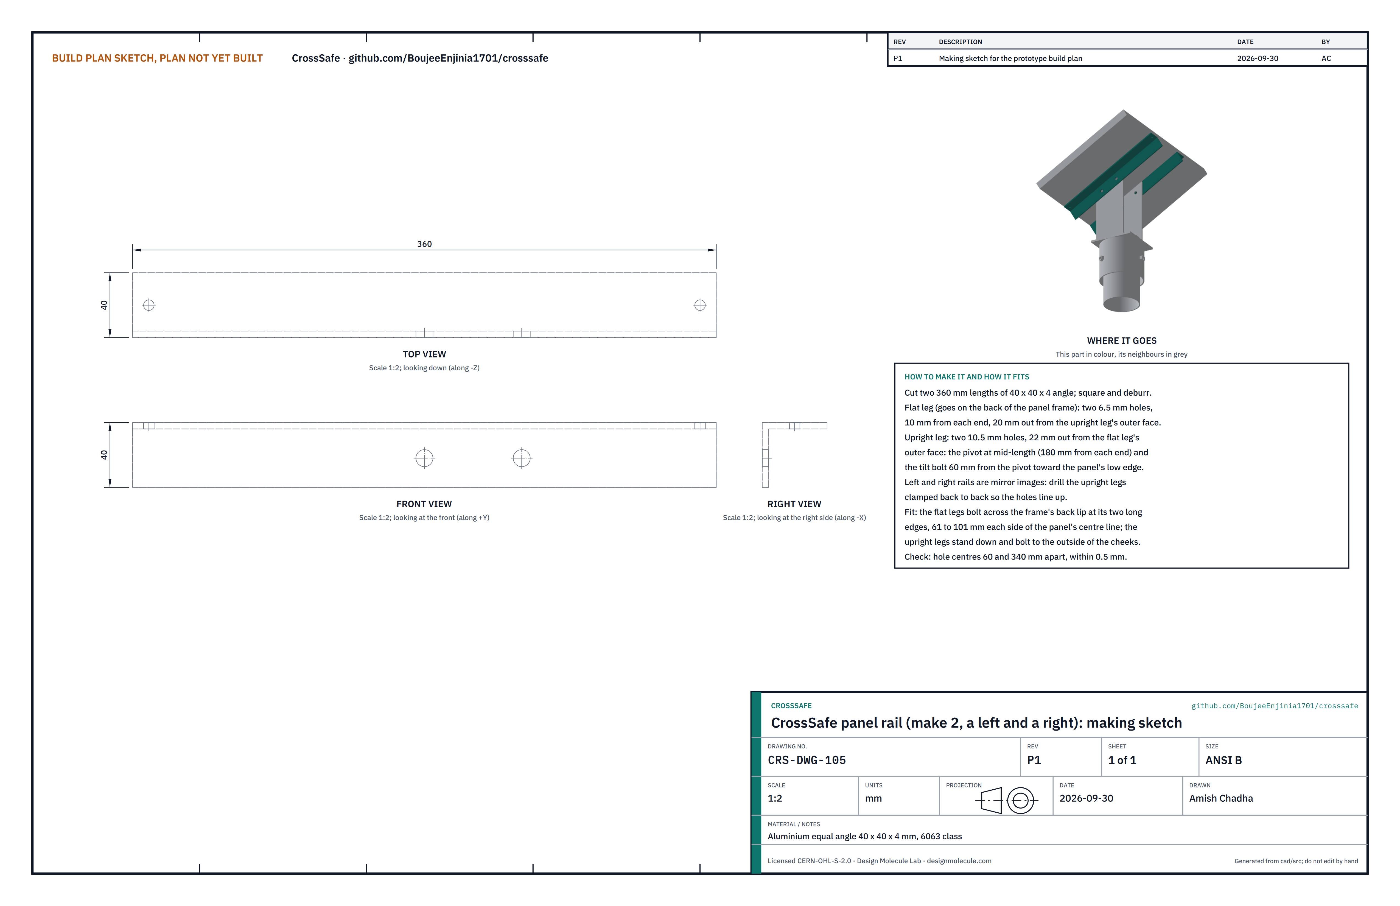
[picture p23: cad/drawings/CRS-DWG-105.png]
Figure 13. Making sketch of the panel rail


*Figure 13. Panel rail making sketch (CRS-DWG-105).*

**What it is and what it is made from.** Two angles bolted across the back of the panel frame that hang the panel on the bracket's cheeks. Aluminium equal angle 40 x 40 x 4, 6063 class.

**How to make it.**

1. Cut two 360 lengths; square and deburr the ends.
2. Flat leg (the one that goes on the panel frame): two 6.5 holes, 10 from each end, 20 out from the outer face of the upright leg.
3. Upright leg: two 10.5 holes, 22 out from the outer face of the flat leg: the pivot hole at mid-length (180 from each end) and the tilt bolt hole 60 from it, toward the end that will be at the panel's low edge.
4. The two rails are mirror images: clamp the upright legs back to back and drill them together so the holes line up.

**How it fits the parts next to it.**

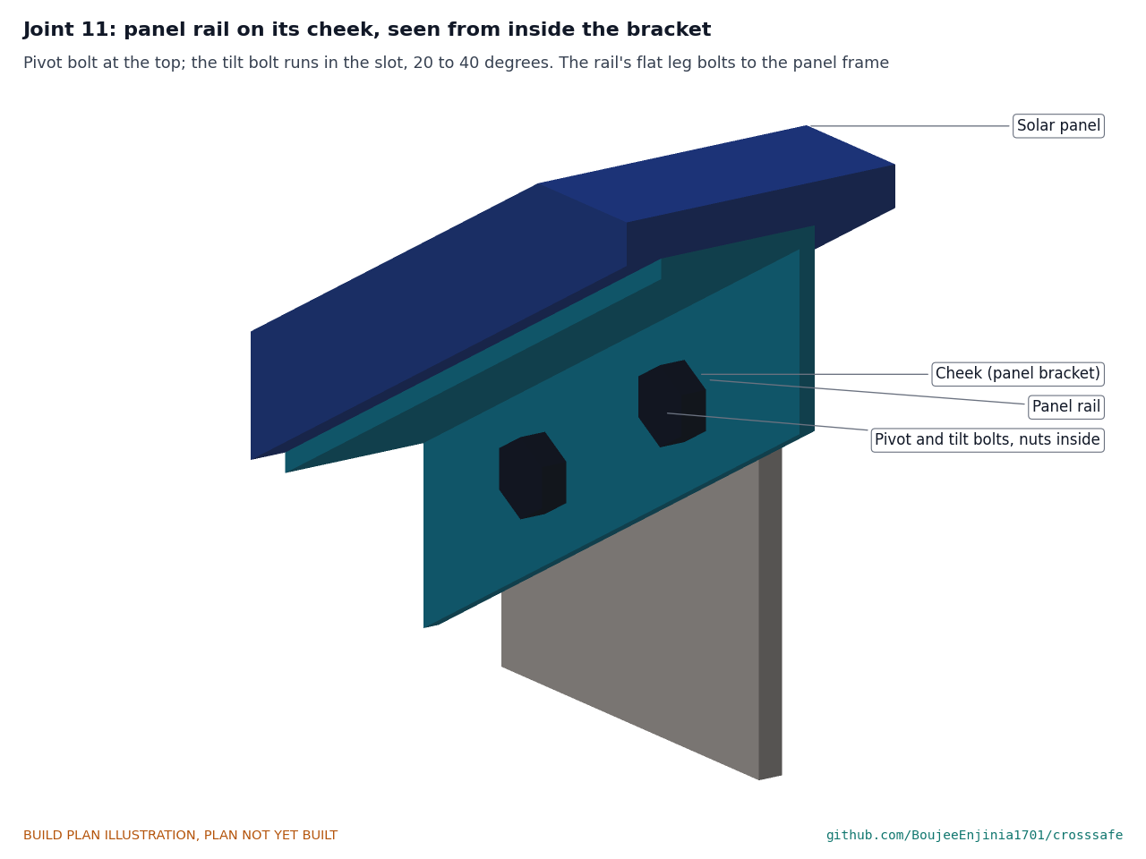
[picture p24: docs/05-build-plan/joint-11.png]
Figure 14. Joint 11: a rail on its cheek, seen from inside the bracket


*Figure 14. The pivot bolt and the tilt bolt pass through the rail and the cheek; the nuts are inside the bracket.*

The flat legs lie across the frame's back lip at the panel's two long edges, 61 to 101 each side of the panel's centre line, with two M6 bolts each (nuts inside the frame). The upright legs stand down from the panel, against the outside faces of the bracket's two cheeks: an M10 pivot bolt at the top of each cheek, and an M10 bolt in each cheek's tilt slot.

**Check before moving on.** Hole centres 60 and 340 apart, within 0.5. The panel you buy must have a flat back lip at least 15 wide on its long edges.

### 3.6 Keyed pole saddles (make 8, all the same)

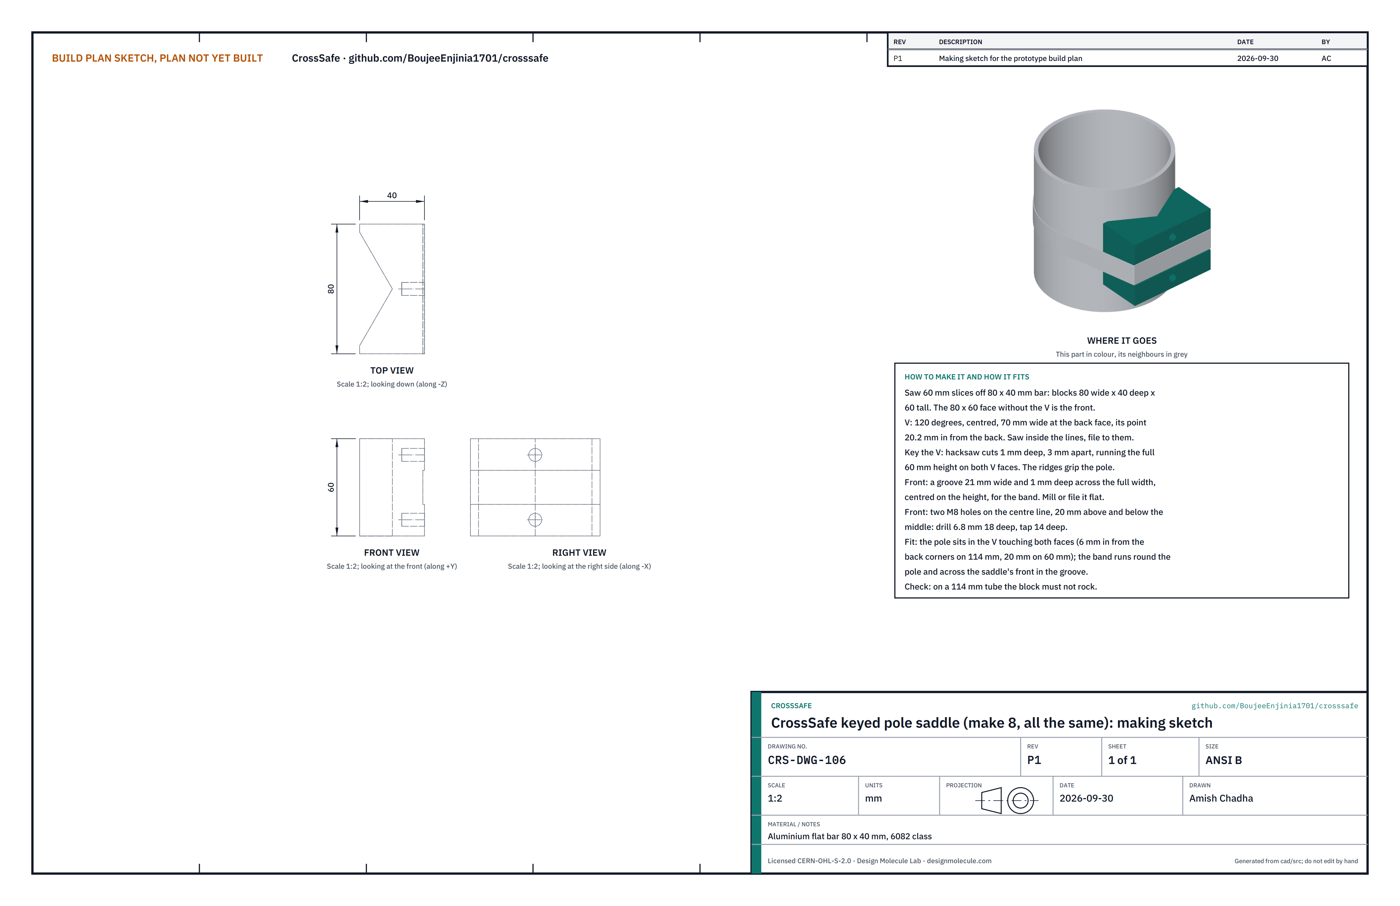
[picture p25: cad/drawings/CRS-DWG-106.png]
Figure 15. Making sketch of the keyed pole saddle


*Figure 15. Keyed pole saddle making sketch (CRS-DWG-106).*

**What it is and what it is made from.** The block every part on the pole is fixed to: a V in its back sits on the pole, the band runs across its front, and the part bolts to its front over the band. Aluminium flat bar 80 x 40, 6082 class.

**How to make it.**

1. Saw eight slices 60 thick off the bar and file each to 80 wide, 40 deep and 60 tall. The 80 x 60 face without the V is the front.
2. On each 80 x 40 face, scribe the V: 120° included, centred, 70 wide at the back face, with its point 20.2 in from the back face. Saw just inside both lines and file to them.
3. Key the V faces: hacksaw cuts 1 deep and 3 apart, running the full 60 height on both faces. The ridges bite into the pole's coating and resist the sign turning.
4. Across the front, file or mill a groove 21 wide and 1 deep, centred on the 60 height, for the band.
5. On the front's centre line, 20 above and 20 below the middle, drill 6.8 to 18 deep and tap M8 to 14 deep.
6. Break every sharp edge.

**How it fits the parts next to it.**

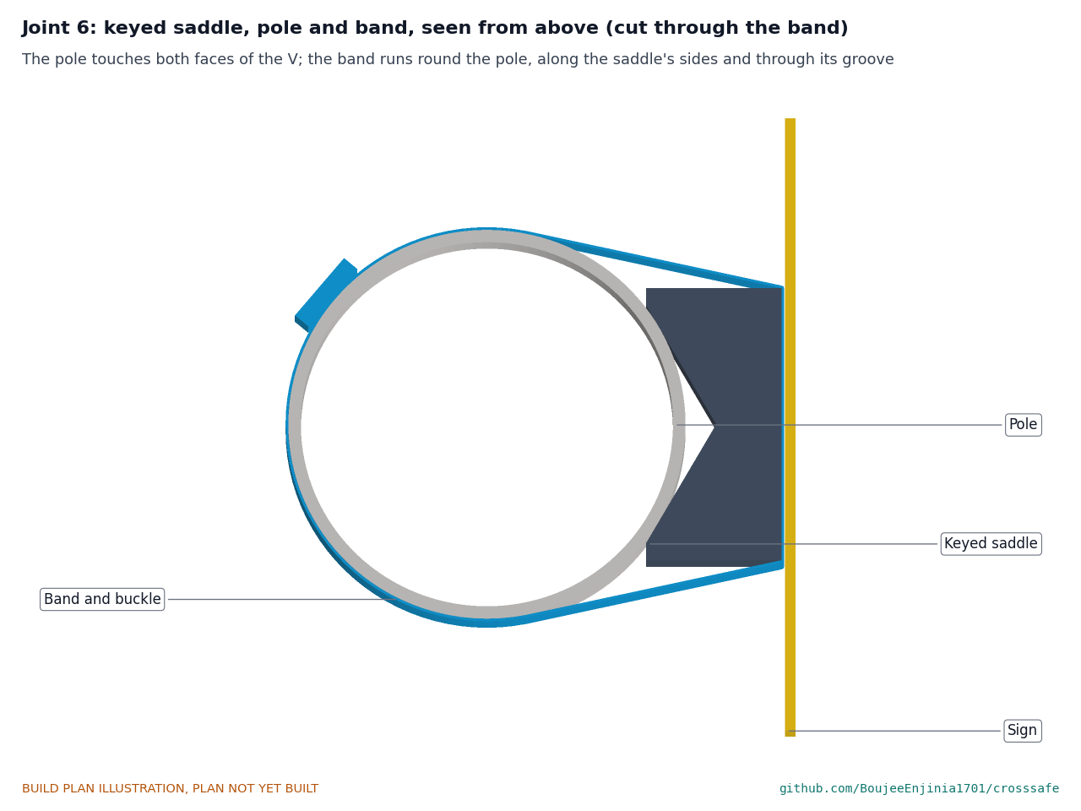
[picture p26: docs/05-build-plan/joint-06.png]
Figure 16. Joint 6: saddle, pole and band seen from above


*Figure 16. Cut through the band. The pole touches both faces of the V; the band runs round the pole and across the saddle's front in its groove.*

The pole touches both V faces, 6.4 in from the back corners on a 114.3 pole and 20 in on a 60 pole; the saddle's front is then 28.6 in front of a 114.3 pole's surface. The band (19 x 0.76 stainless, with a buckle) goes round the back of the pole, runs straight to the saddle's front corners and lies in the groove; tightening it pulls the V onto the pole. The buckle sits behind the pole, turned off the centre line. Whatever bolts to the saddle covers the band:

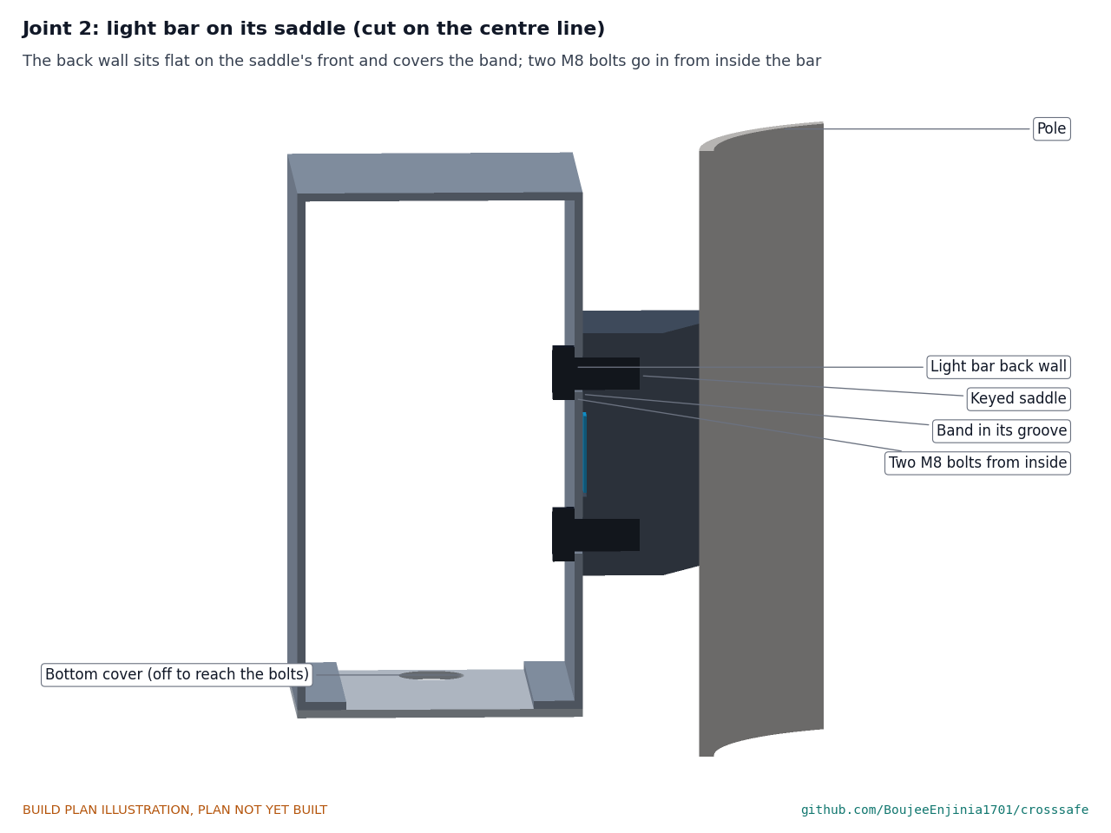
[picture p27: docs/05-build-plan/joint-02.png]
Figure 17. Joint 2: the light bar on its saddle


*Figure 17. The light bar's back wall sits flat on the saddle; two M8 bolts go in from inside the bar.*

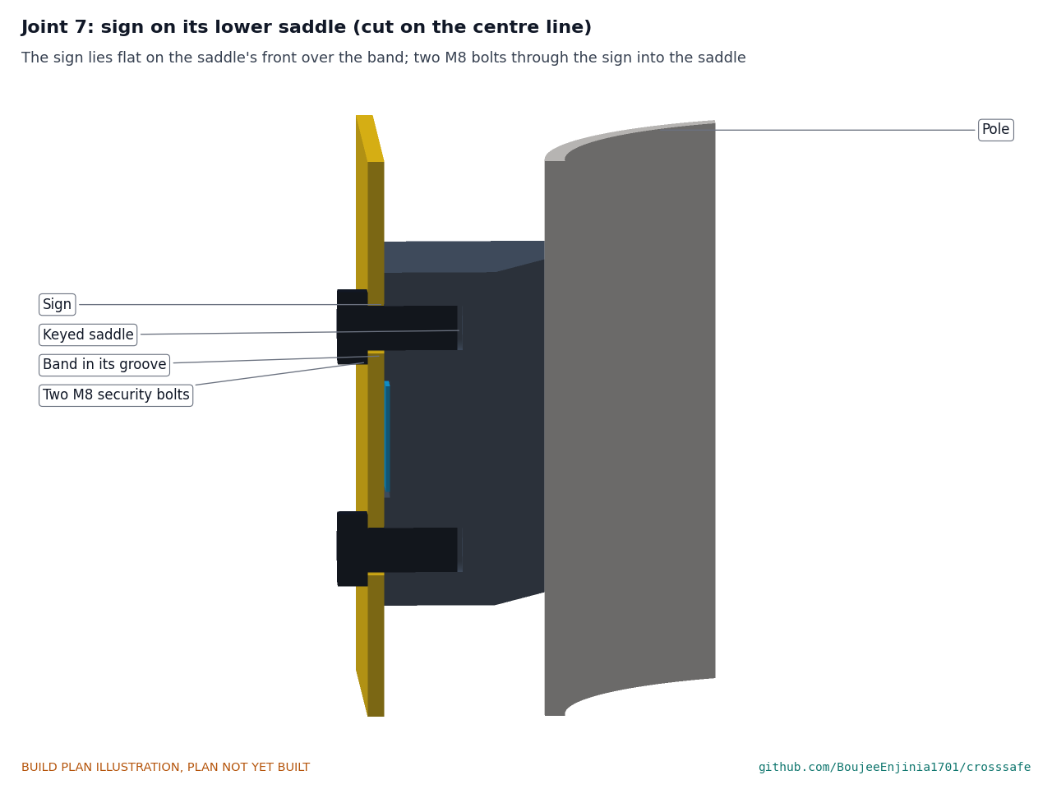
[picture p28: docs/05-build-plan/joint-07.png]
Figure 18. Joint 7: the sign on its lower saddle


*Figure 18. The sign lies flat on the saddle's front; two M8 security bolts go through it into the saddle.*

On a new post (not this prototype), the upper sign saddle's upper hole is drilled right through at 10.5 and one M10 bolt passes through the sign, the saddle and both walls of the post, which stops the sign turning:

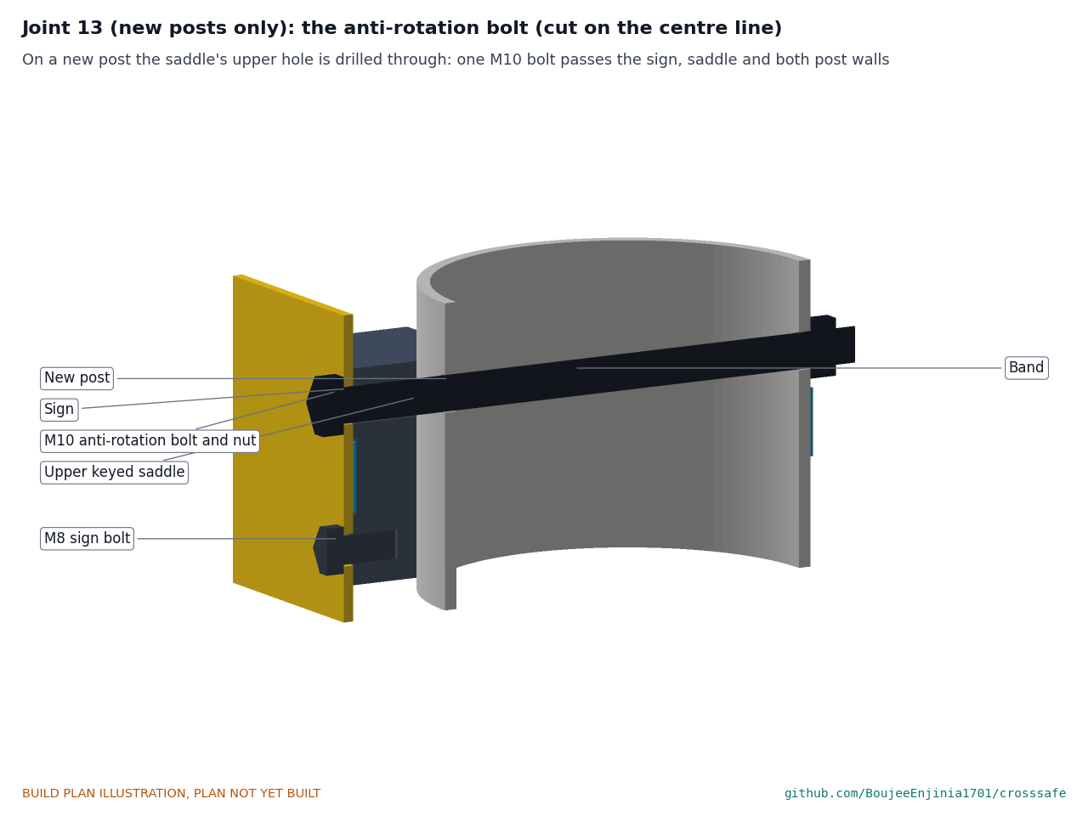
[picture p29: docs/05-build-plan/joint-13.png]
Figure 19. Joint 13: the anti-rotation bolt on a new post


*Figure 19. New posts only: the M10 bolt in place of one sign bolt, nyloc nut behind the post.*

**Check before moving on.** On a 114 tube each saddle must not rock; a 60 tube must also touch both V faces; both tapped holes take an M8 bolt by hand.

### 3.7 Radar arm

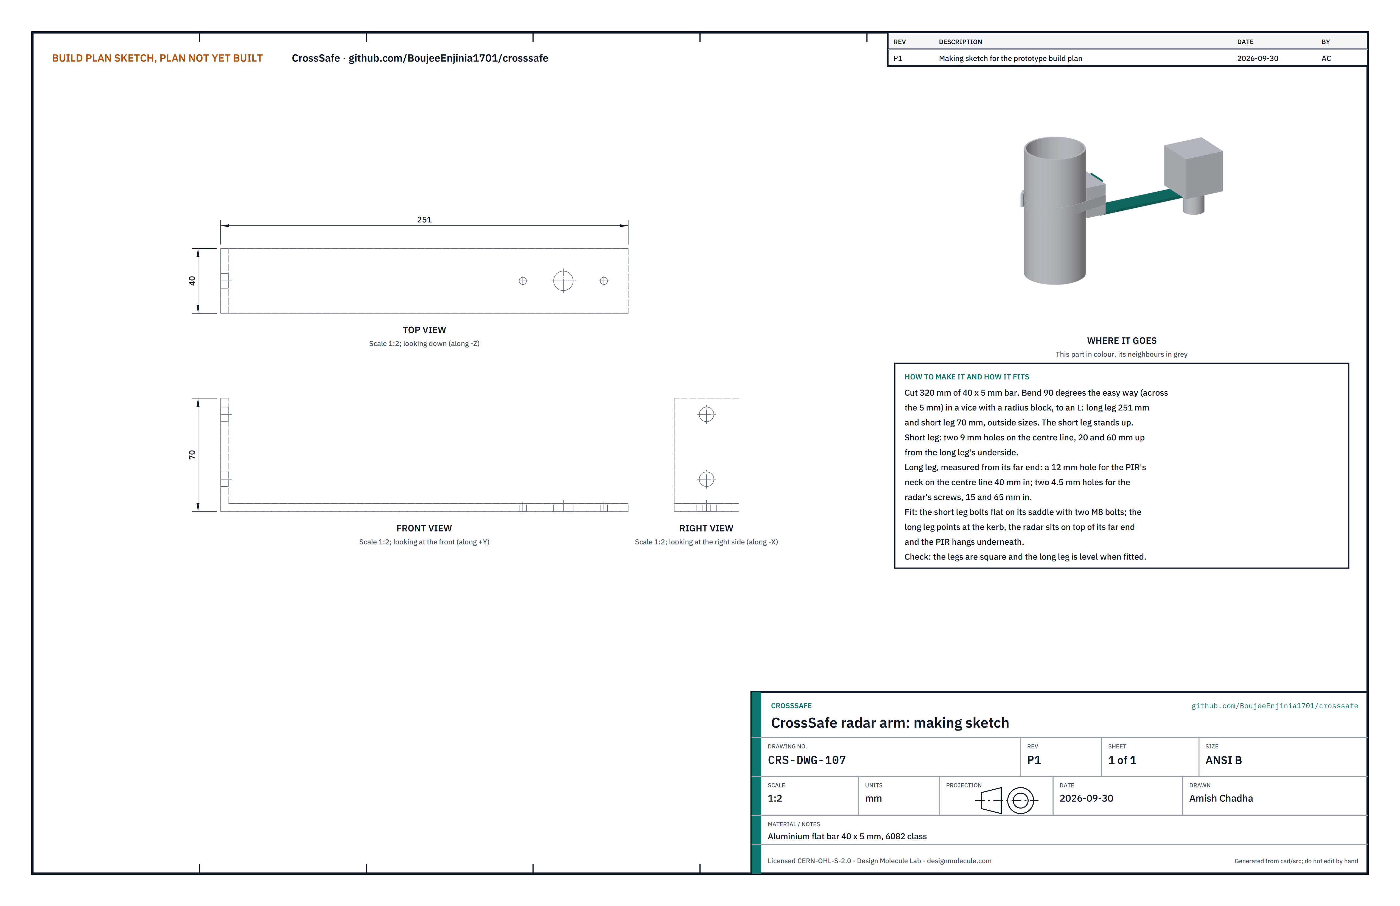
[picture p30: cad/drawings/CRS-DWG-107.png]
Figure 20. Making sketch of the radar arm


*Figure 20. Radar arm making sketch (CRS-DWG-107).*

**What it is and what it is made from.** An L-shaped arm that holds the radar and the PIR sensor out over the kerb side, 240 from the pole. Aluminium flat bar 40 x 5, 6082 class.

**How to make it.**

1. Cut 320 of bar. Bend it 90° across the 5 thickness in a vice over a radius block, to an L with outside legs of 251 and 70.
2. Short leg: two 9 holes on its centre line, 20 and 60 up from the underside of the long leg.
3. Long leg, measured from its far end: a 12 hole on the centre line 40 in, for the PIR's neck; two 4.5 holes on the centre line 15 and 65 in, for the radar housing's screws.
4. Deburr.

**How it fits the parts next to it.**

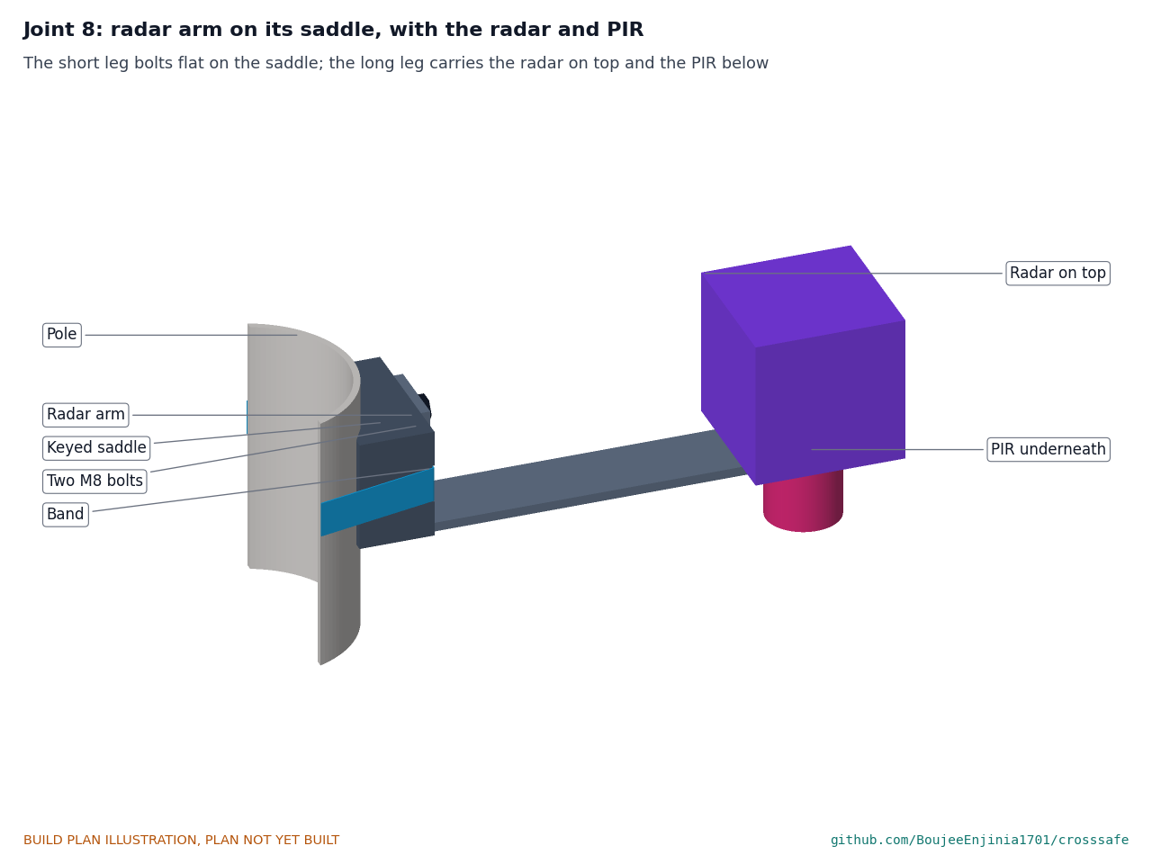
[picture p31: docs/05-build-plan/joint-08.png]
Figure 21. Joint 8: the radar arm on its saddle, with the radar and the PIR


*Figure 21. The short leg stands up flat on the saddle; the radar sits on the far end of the long leg and the PIR hangs under it.*

The short leg sits flat on its saddle with two M8 bolts. The long leg points at the kerb, level, 2,555 above the sidewalk at its underside. The radar housing sits on top of its far end with two M4 screws; the PIR's threaded neck passes up through the 12 hole and its nut goes on top. The PIR's underside is 2,515 above the sidewalk.

**Check before moving on.** The legs are square; with the arm on a saddle on a vertical tube, the long leg is level within 1°.

### 3.8 Panel bracket

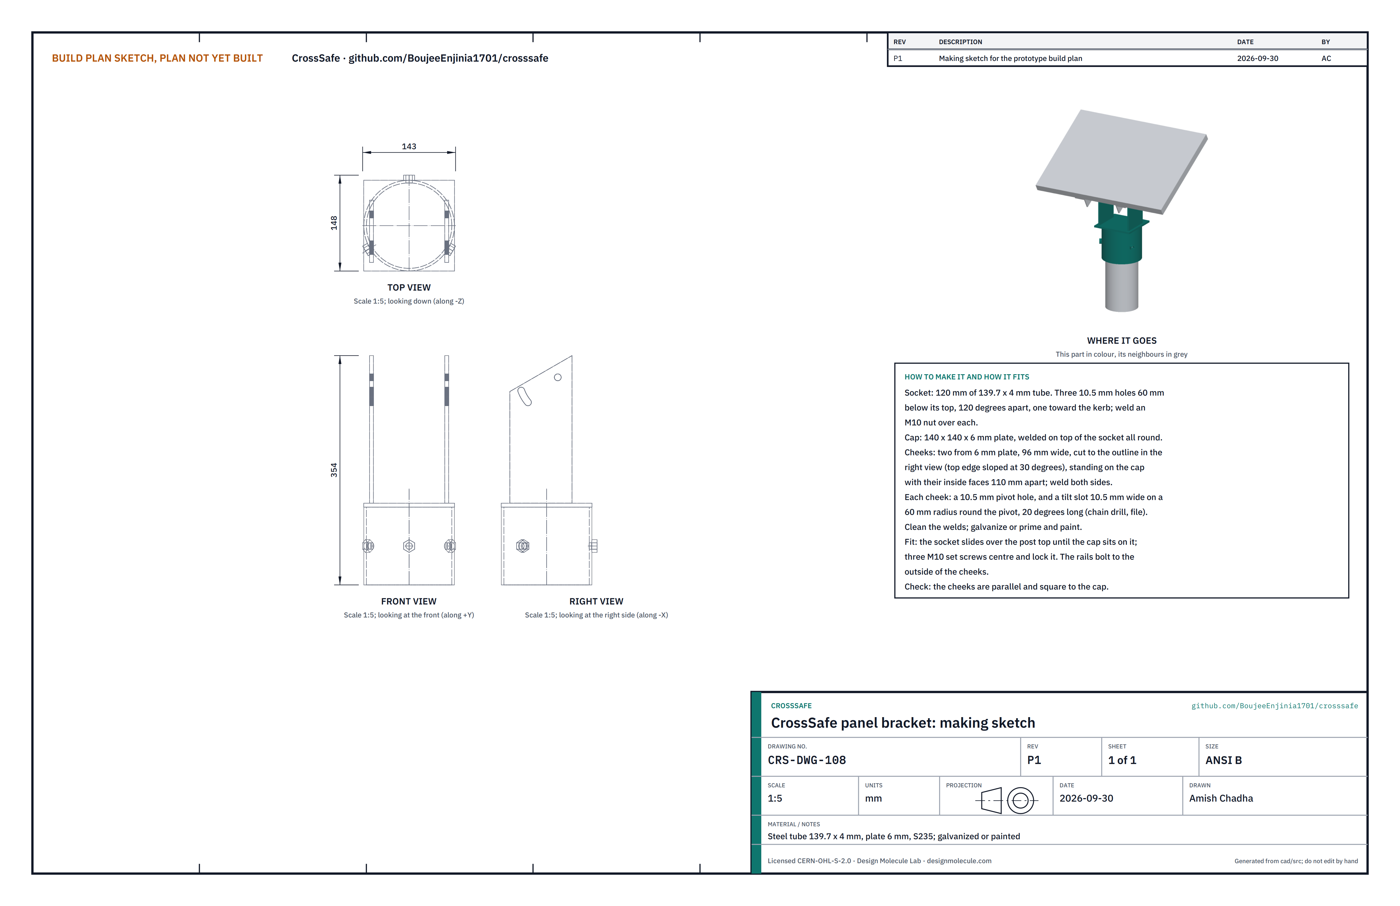
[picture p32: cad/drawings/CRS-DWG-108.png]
Figure 22. Making sketch of the panel bracket


*Figure 22. Panel bracket making sketch (CRS-DWG-108).*

**What it is and what it is made from.** The welded steel bracket on the post top that carries the panel at 30°. Steel tube 139.7 x 4 and plate 6, S235, galvanized or painted after welding.

**How to make it.**

1. Socket: cut 120 of 139.7 x 4 tube. Drill three 10.5 holes 60 below its top, 120° apart, one toward the kerb side. Weld an M10 nut over each hole on the outside.
2. Cap: cut 140 x 140 from 6 plate and weld it on top of the socket all round.
3. Cheeks: cut two from 6 plate to the outline of the right view in Figure 22, 96 wide, with the top edge sloping at 30°. In each, drill the 10.5 pivot hole, and chain drill and file the tilt slot: 10.5 wide, on a 60 radius round the pivot, 20° long.
4. Stand the cheeks on the cap with their inside faces 110 apart, parallel to each other and square to the cap, and weld both sides of each.
5. Clean the welds; send for hot-dip galvanizing, or prime and paint.

**How it fits the parts next to it.**

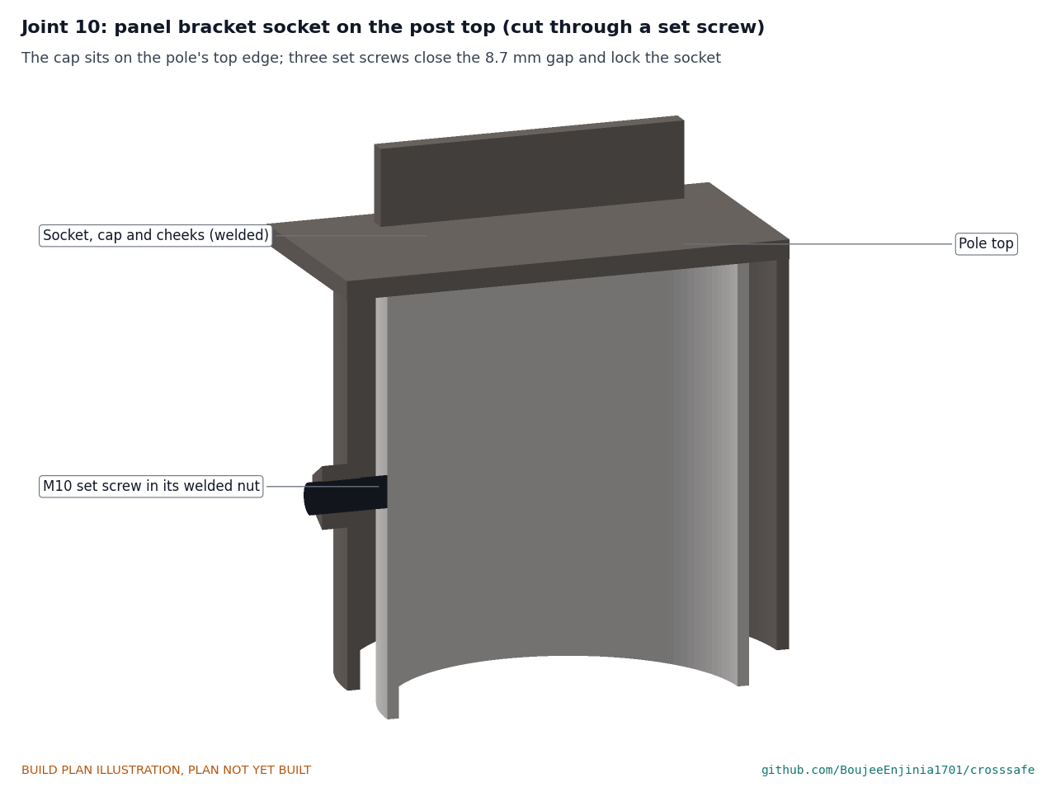
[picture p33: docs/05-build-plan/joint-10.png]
Figure 23. Joint 10: the socket on the post top


*Figure 23. The cap rests on the pole's top edge; three set screws close the 8.7 gap round the pole and lock the socket.*

The socket slides over the pole top until the cap sits on it; three M10 security set screws through the welded nuts centre it and lock it. The panel rails bolt to the outside of the cheeks (Figure 14).

**Check before moving on.** The cheeks are parallel within 1 and square to the cap; the socket slides over a 114.3 tube.

### 3.9 Sun shield

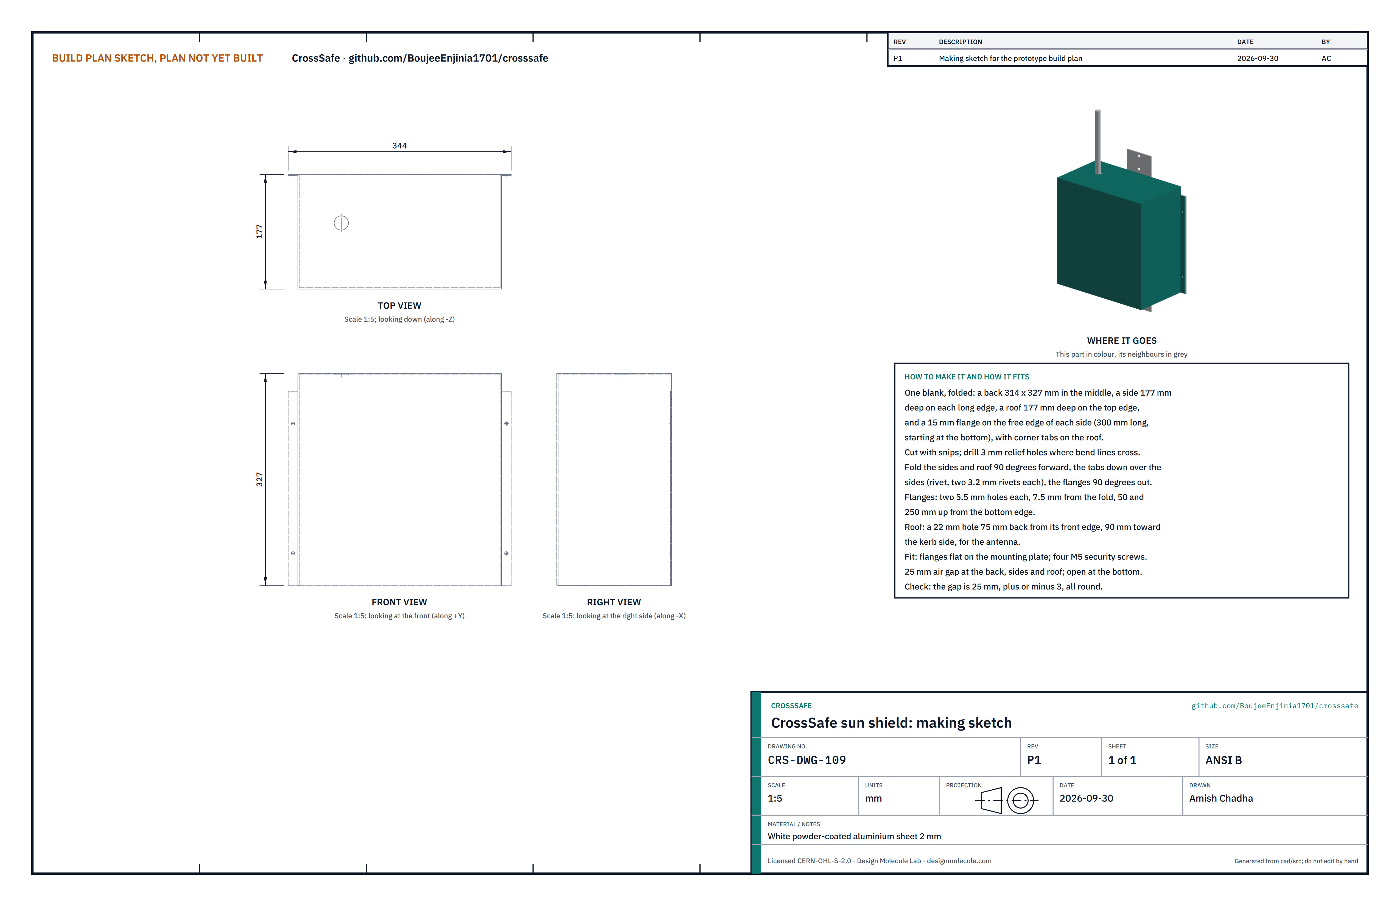
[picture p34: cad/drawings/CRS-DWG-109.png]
Figure 24. Making sketch of the sun shield


*Figure 24. Sun shield making sketch (CRS-DWG-109).*

**What it is and what it is made from.** A white folded sheet that shades the enclosure on its back, sides and roof with a 25 air gap, open at the bottom and, above the mounting plate, toward the pole. White powder-coated aluminium sheet 2 mm.

**How to make it.**

1. Mark one blank on the protective film: the back, 314 x 327, in the middle; a side 177 deep on each long edge; a roof 177 deep on the top edge with a 10 tab on each end; and a 15 flange along the free edge of each side, 300 long from the bottom.
2. Cut with aviation snips. Drill a 3 relief hole wherever two fold lines cross, so the coating does not tear.
3. Fold the sides and the roof 90° forward, then the roof tabs down over the sides, and rivet each tab with two 3.2 rivets. Fold each flange 90° outward.
4. Flanges: two 5.5 holes each, 7.5 from the fold, 50 and 250 up from the bottom edge.
5. Roof: a 22 hole, 75 back from its front edge and 90 toward the kerb side, for the antenna.
6. Peel the film.

**How it fits the parts next to it.**

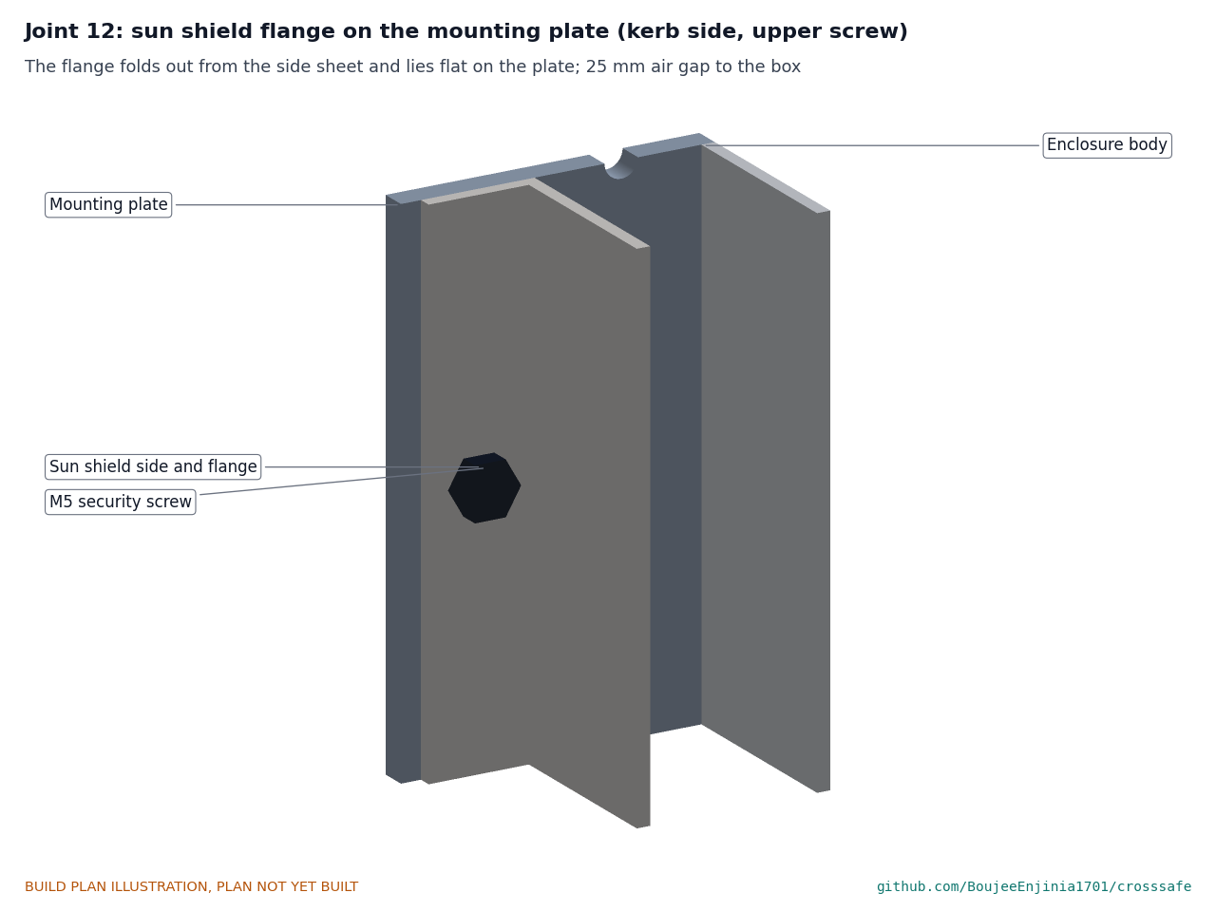
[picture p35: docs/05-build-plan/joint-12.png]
Figure 25. Joint 12: a shield flange on the mounting plate


*Figure 25. The flange lies flat on the mounting plate beside the box and takes an M5 security screw.*

The flanges lie flat on the mounting plate either side of the box and take four M5 security screws into the plate's tapped holes. The shield stands 25 off the enclosure's back, sides and roof; the antenna passes through the roof hole with 3 to spare all round. To open the enclosure lid, undo the four screws and lift the shield away.

**Check before moving on.** On a trial fit over the box, the gap is 25, give or take 3, all round.

### 3.10 Bought components

Buy to specification, not brand. Line numbers are those of the bill of materials.

- **Crossing warning sign (line 1).** 750 diamond, 3 aluminium, retroreflective sheeting to the local sign design, without the maker's brackets. Drill four 9 holes on its vertical centre line, 260, 300, 760 and 800 up from its bottom point.
- **LED heads (line 3).** Four amber modules, lens 140 x 62 (at least 127 x 51 lit), about 6 W at 12 V, dimmable, each with a flange that covers a 128 x 50 window and a body no deeper than 25 behind it, bought with a snap-on bezel frame and a moulded hood visor 26 deep with a drip lip.
- **Push-button station and instruction plate (line 4).** Vandal-resistant piezo button with tone, tactile arrow and LED, in a housing about 70 x 60 x 160 that fixes to a flat face with two bolts; an instruction plate 230 x 300 x 4. Drill two 9 holes in the plate on its centre line, 130 and 170 up from its bottom edge.
- **Radar (line 5) and PIR sensor (line 16).** 24 GHz presence radar in a housing about 80 x 80 x 80 with two screws 50 apart in its base; low-power PIR with a threaded neck of 12 or less.
- **Solar panel (line 6).** 20 W monocrystalline, about 500 x 360 x 25, aluminium frame with a flat back lip at least 15 wide on the long edges.
- **Enclosure (line 8).** As section 3.2.
- **Battery (line 9).** LiFePO4 12.8 V 12 Ah with its own battery management system and low-temperature charge protection, no larger than 151 x 95 x 98.
- **Charger (line 10).** 12 V MPPT charger, 5 A class, LiFePO4 profile, low-temperature charge cut-off, own use 4 mA or less, no larger than 40 x 90 x 60.
- **Controller and radio board (line 11).** FieldNode radio core (STM32WL-class LoRa module) on its maker's breakout, with four LED driver channels with night dimming, a clock, a fault LED and a 12 V to 3.3 V converter, on a board no larger than 180 x 100.
- **Antenna (line 12).** Short whip for the LoRa band of the pilot region, with a 16 bulkhead.
- **Bands (line 13).** Eight 19 x 0.76 stainless bands, about 0.6 long each, with buckles, and a banding tool.
- **Pilot light (line 17).** Small amber panel-mount light, about 0.3 W, with a lens about 30 across and a threaded body for a 22 hole.
- **Wiring and fixings (line 15).** Outdoor cable; a fuse block with a 5 A battery fuse and a 2 A controller fuse; four M20 and one M16 nylon glands with blanking plugs; stainless security fixings: 20 M8 x 16 bolts, 4 M5 x 12 screws with nyloc nuts, 4 M5 x 10 screws, 4 M6 x 12 bolts with nuts, 4 M10 x 30 bolts with nyloc nuts, 3 M10 set screws; M4 and M3 screws, rivet nuts and 3.2 rivets, nylon stand-offs, ferrules, cable ties and a cable cover for the pole.

## 4. Putting it together

In each picture the parts already fitted are grey and the part being fitted is in colour, with an arrow showing the way it goes in. Steps 1 to 7 are bench work. For steps 8 to 18 the test post lies on two trestles at bench height, turned as each step needs; the pictures show it upright.

### Step 1: LED heads and pilot light into the light bar

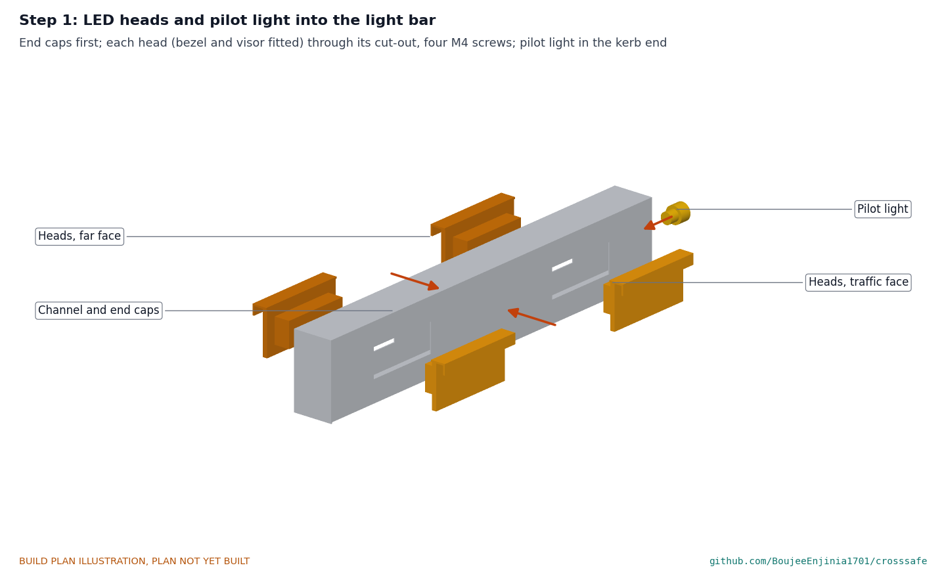
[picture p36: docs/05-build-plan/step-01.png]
Step 1


End caps riveted on first. Each head, with its bezel and visor already on it, from outside through its window, four M4 screws. The pilot light through the kerb-end cap, its nut inside. Lead every wire to the cable gland's position.

### Step 2: close the light bar

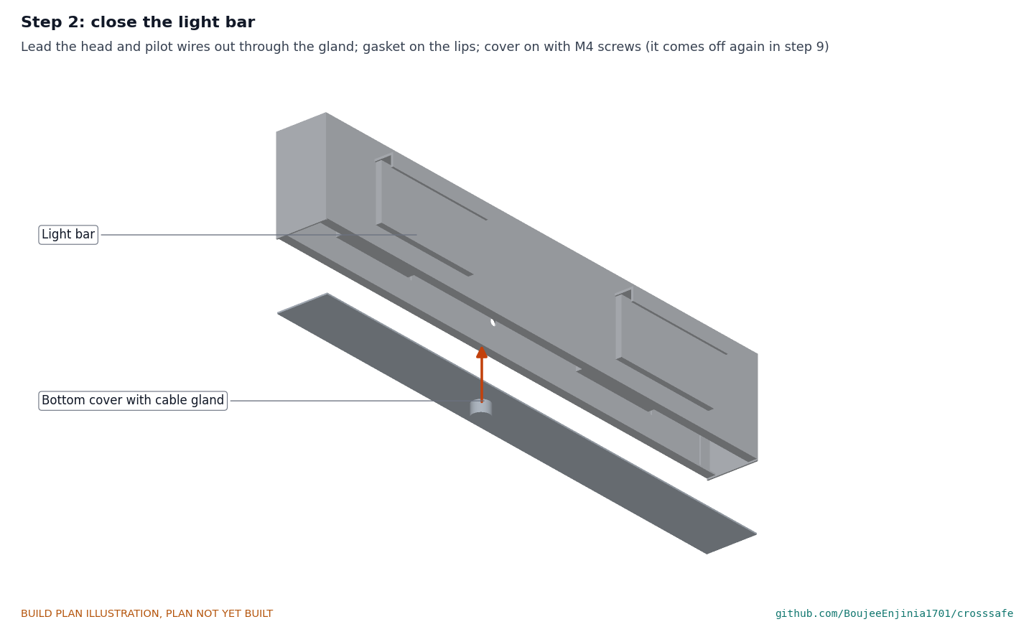
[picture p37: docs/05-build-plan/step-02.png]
Step 2


Fit the M16 gland in the cover and lead the head and pilot wires out through it. Foam gasket on the lips; cover on with its M4 screws. It comes off again in step 9.

### Step 3: glands, vent and antenna into the enclosure

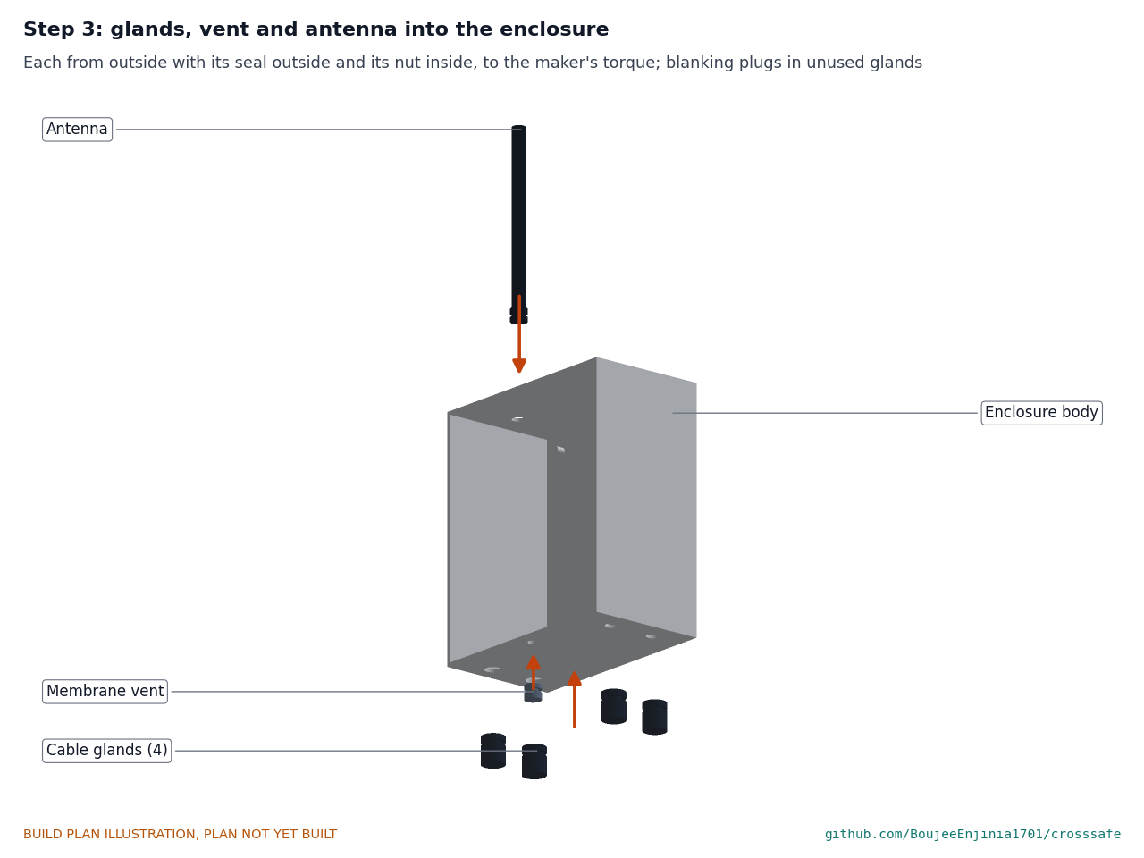
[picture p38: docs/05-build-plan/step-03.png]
Step 3


Each from outside with its seal outside and its nut inside, to the maker's torque. Blanking plugs in the glands until their cables arrive.

### Step 4: build the internal plate

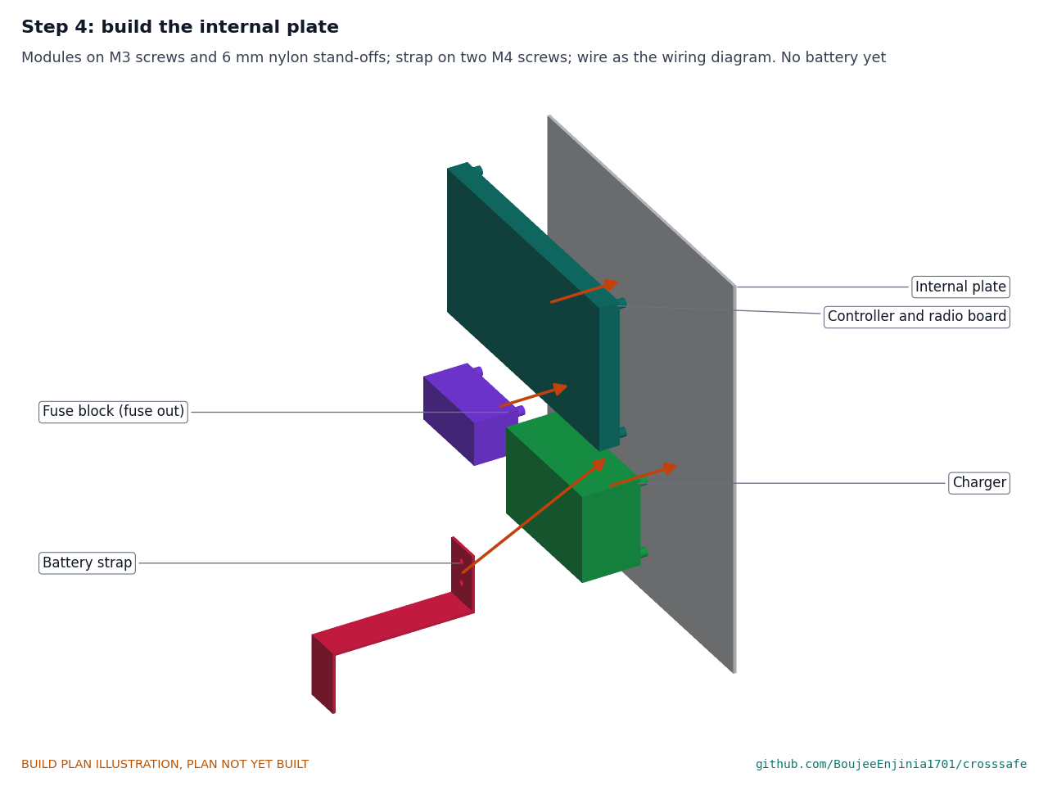
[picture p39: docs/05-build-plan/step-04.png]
Step 4


Charger, controller board and fuse block on M3 screws and stand-offs; the strap on its two M4 screws; wire them as Figure 8. **Hold point:** no battery, and the fuses out.

### Step 5: internal plate into the enclosure

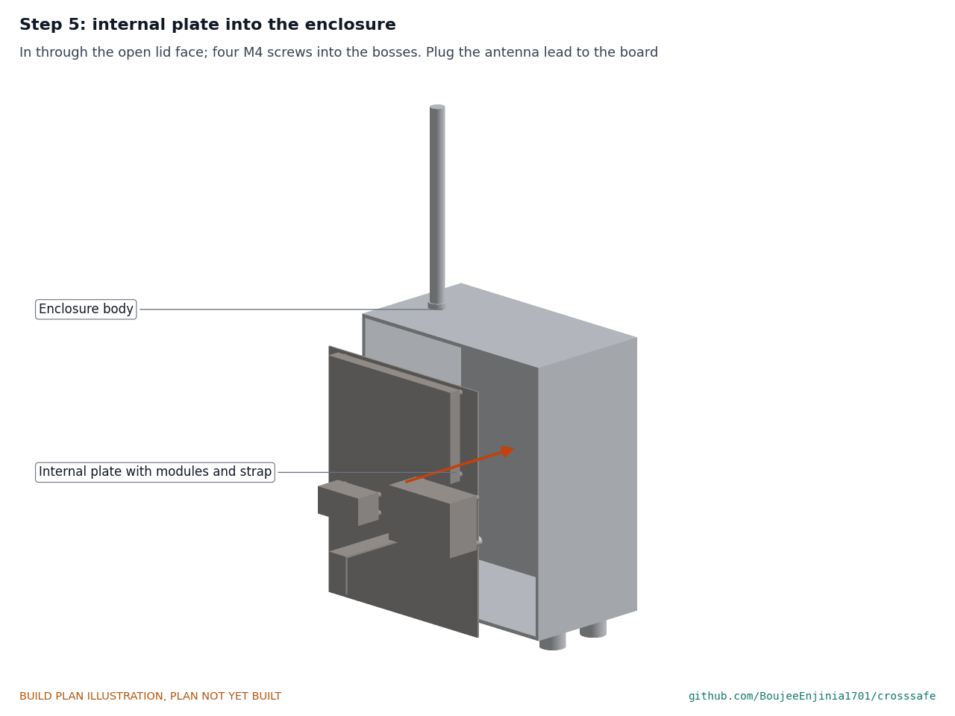
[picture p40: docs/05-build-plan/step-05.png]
Step 5


In through the open lid face, onto the four bosses, four M4 screws. Connect the antenna lead to the board.

### Step 6: enclosure onto the mounting plate

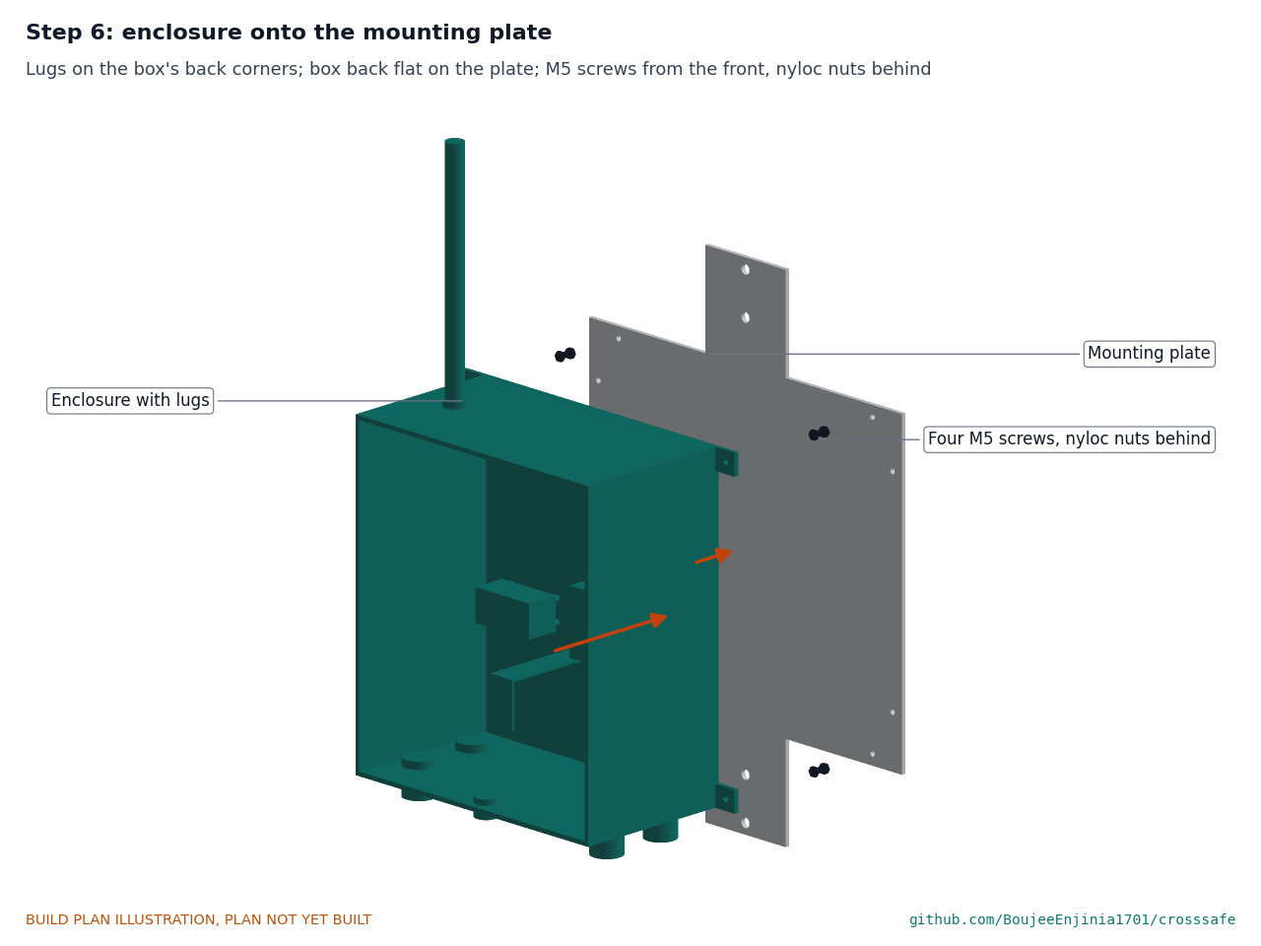
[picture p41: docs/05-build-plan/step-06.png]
Step 6


Lugs on the box's back corners; the box back flat on the plate's front, centred; four M5 screws from the front, nyloc nuts behind, snug.

### Step 7: rails onto the panel

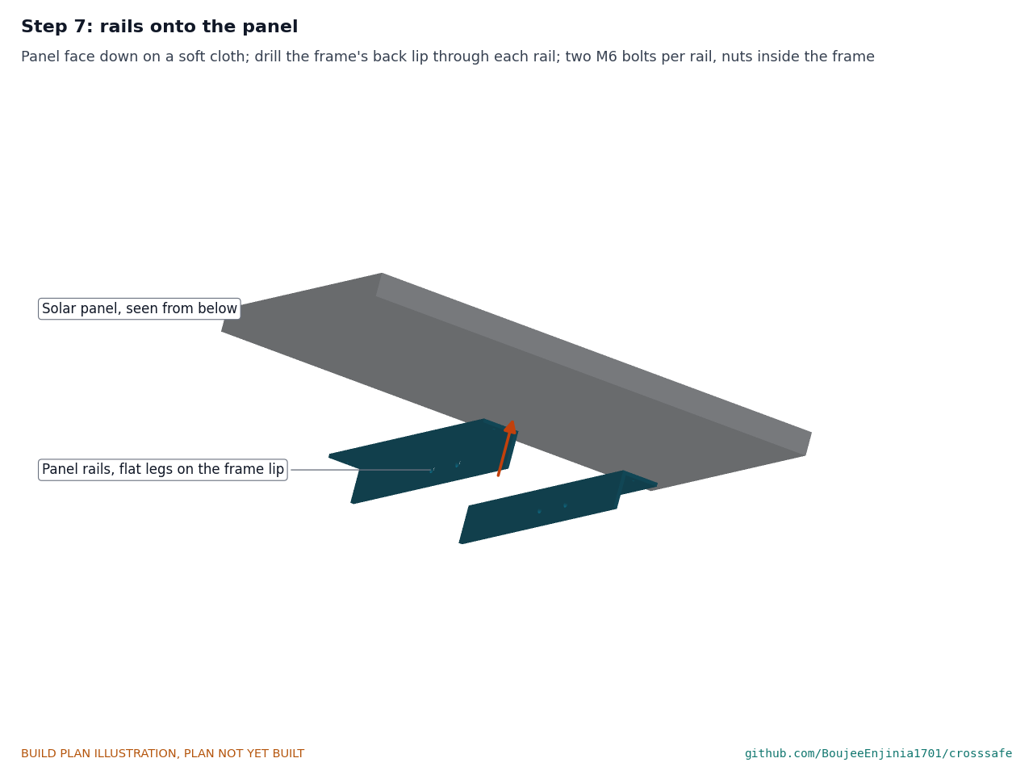
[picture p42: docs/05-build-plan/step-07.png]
Step 7


Lay the panel face down on a soft cloth. Place each rail across the back lip at the long edges, its upright leg 61 from the panel's centre line and pointing away from the panel, drill the lip through the rail's holes, keeping clear of the glass and cells, and fit two M6 bolts with the nuts inside the frame.

### Step 8: saddles and bands onto the post

*Table 2. Saddle heights (the saddle's middle, above the sidewalk; on the test post, above its bottom end) and the way each faces.*

| Saddle | Height | Faces |
| --- | --- | --- |
| Push-button station | 1,050 | Kerb side |
| Instruction plate | 1,300 | Kerb side |
| Light bar | 2,165 | Traffic side |
| Sign, lower | 2,530 | Traffic side |
| Radar arm | 2,595 | Kerb side |
| Enclosure, lower | 2,790 | Back |
| Sign, upper | 3,030 | Traffic side |
| Enclosure, upper | 3,210 | Back |

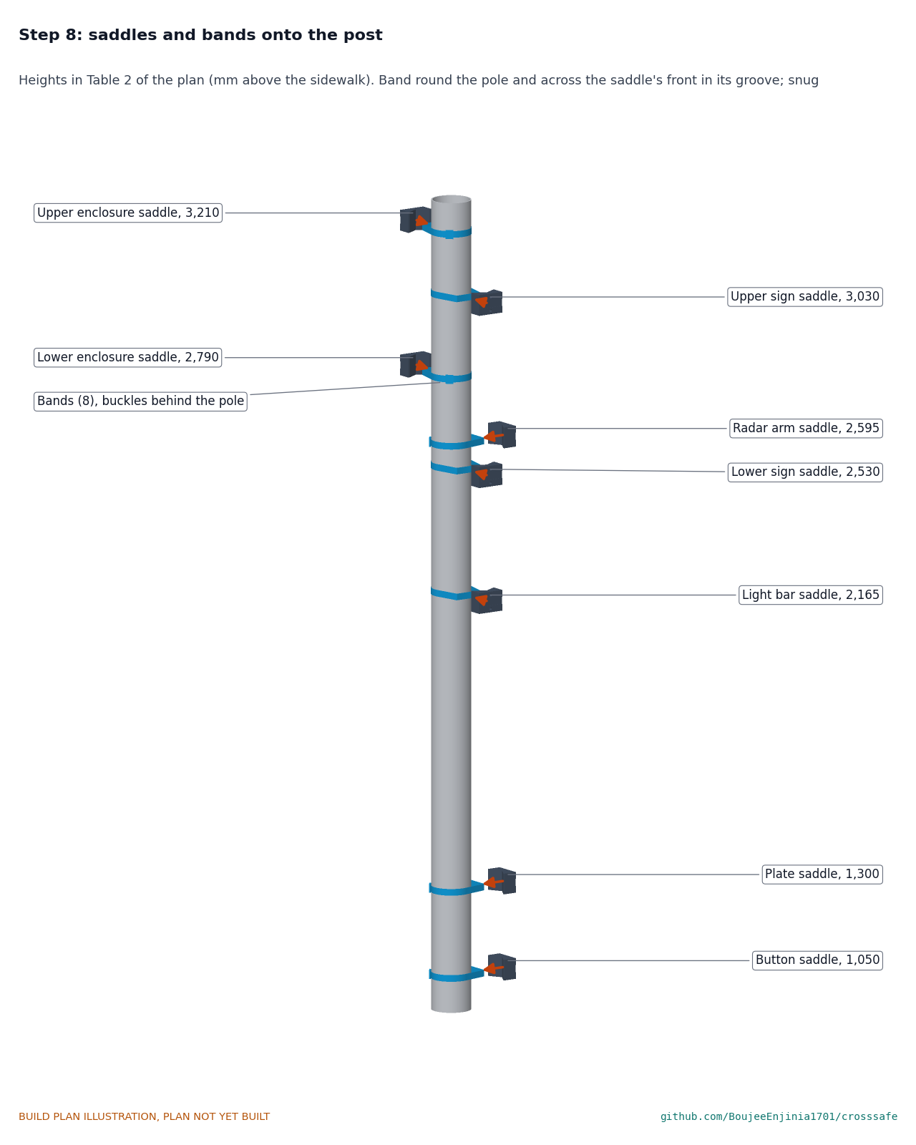
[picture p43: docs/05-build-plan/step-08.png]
Step 8


Mark each height on the post with tape. Each saddle on its mark, facing as Table 2 says; pass its band round the post, across the saddle's front in the groove, and into the buckle behind the post, turned off the centre line. Pull each band snug with the banding tool so the saddle can still be turned by hand; final tension comes in step 10 (sign) and as each part goes on.

### Step 9: light bar onto its saddle

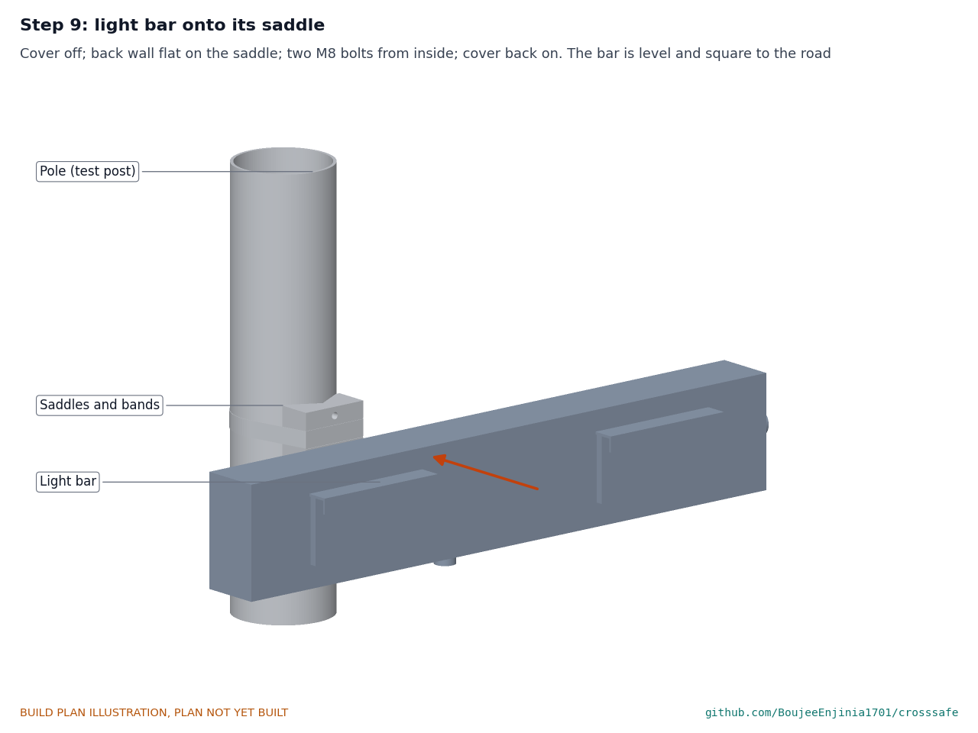
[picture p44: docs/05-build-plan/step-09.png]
Step 9


Cover off; the back wall flat on the saddle, centred; two M8 bolts from inside; cover back on. The bar is level and square to the road. Tension the band.

### Step 10: sign onto its two saddles

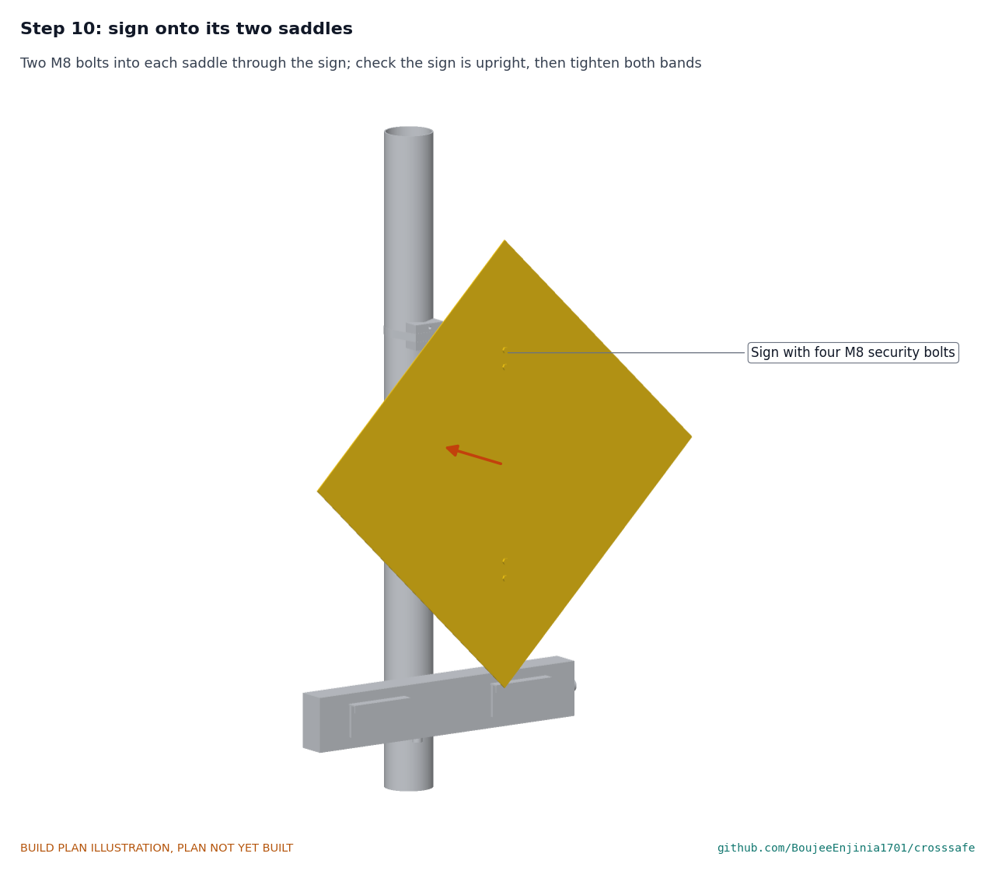
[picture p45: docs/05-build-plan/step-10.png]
Step 10


Two M8 security bolts through the sign into each saddle. Check the sign is upright and square to the road, its bottom point 20 above the light bar, then tension both bands.

### Step 11: push-button station and instruction plate

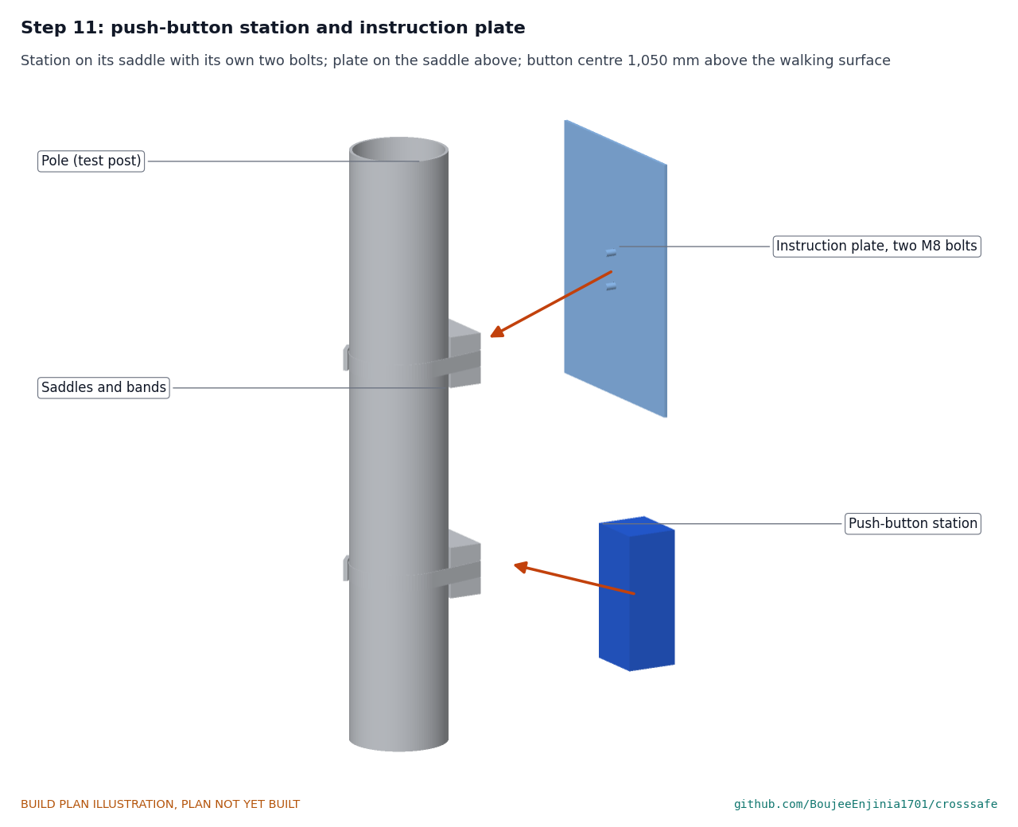
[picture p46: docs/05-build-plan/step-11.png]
Step 11


The station on its saddle with its own two bolts, its button centre 1,050 above the walking surface; the plate on the saddle above with two M8 security bolts. Tension both bands.

### Step 12: radar arm, radar and PIR

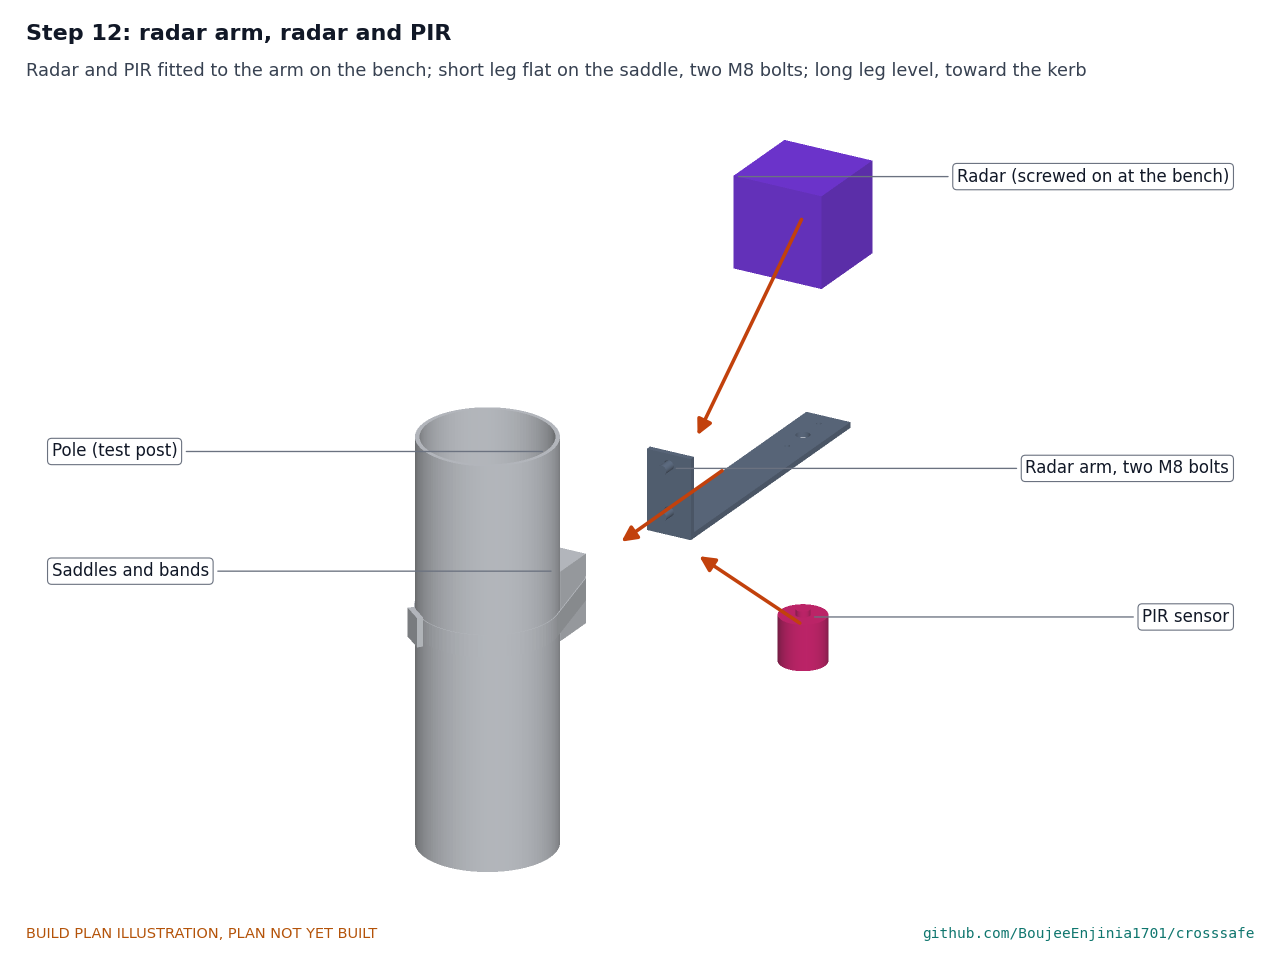
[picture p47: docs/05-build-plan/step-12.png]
Step 12


On the bench, screw the radar onto the arm and fit the PIR under it. Then the short leg flat on its saddle, two M8 bolts, the long leg level and pointing at the kerb. Tension the band.

### Step 13: enclosure unit onto its saddles

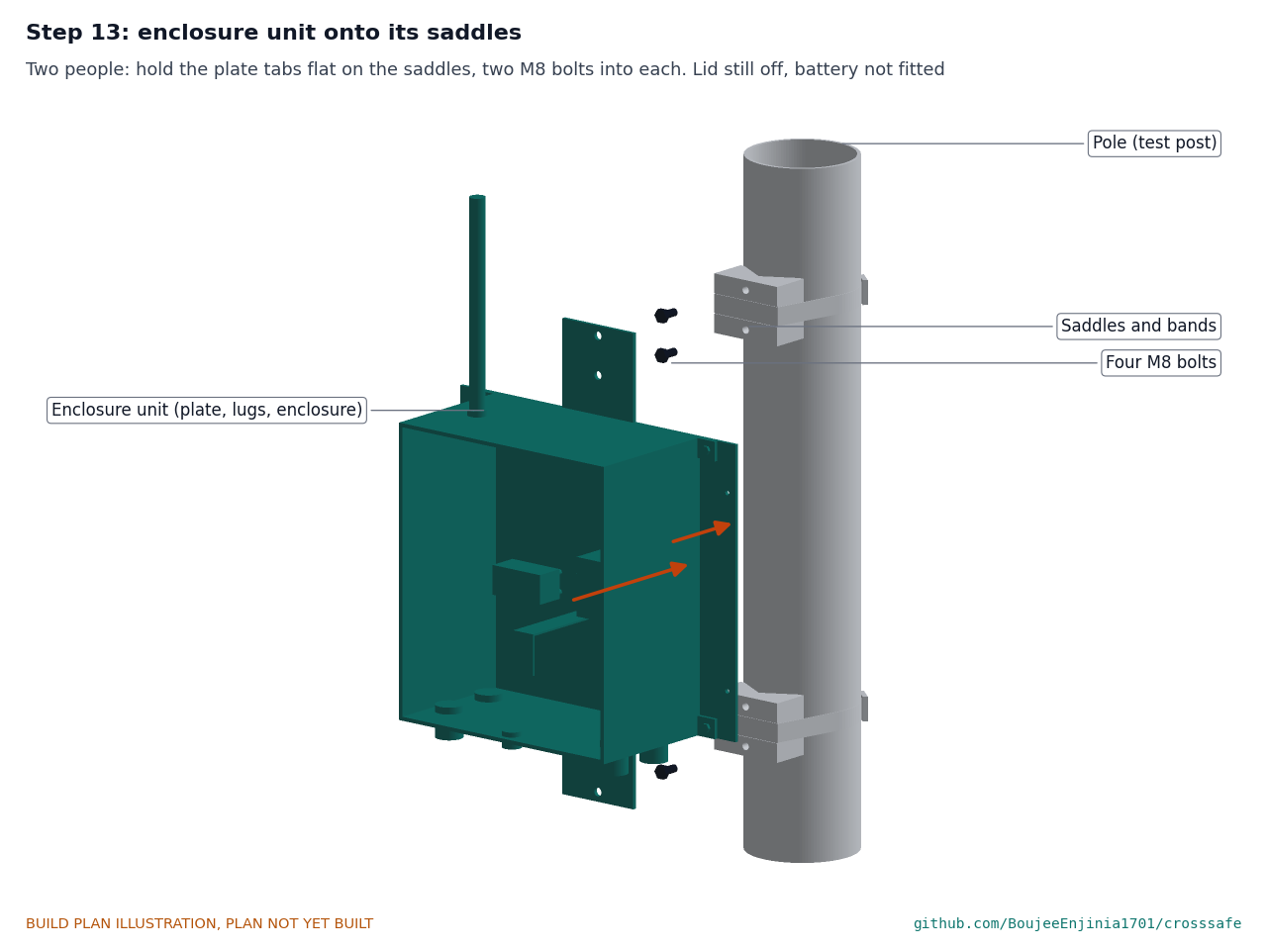
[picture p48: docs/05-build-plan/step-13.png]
Step 13


Two people. Hold the plate's tabs flat on the two back saddles and fit two M8 bolts into each. Lid still off, battery not fitted. Tension both bands.

### Step 14: panel bracket onto the post top

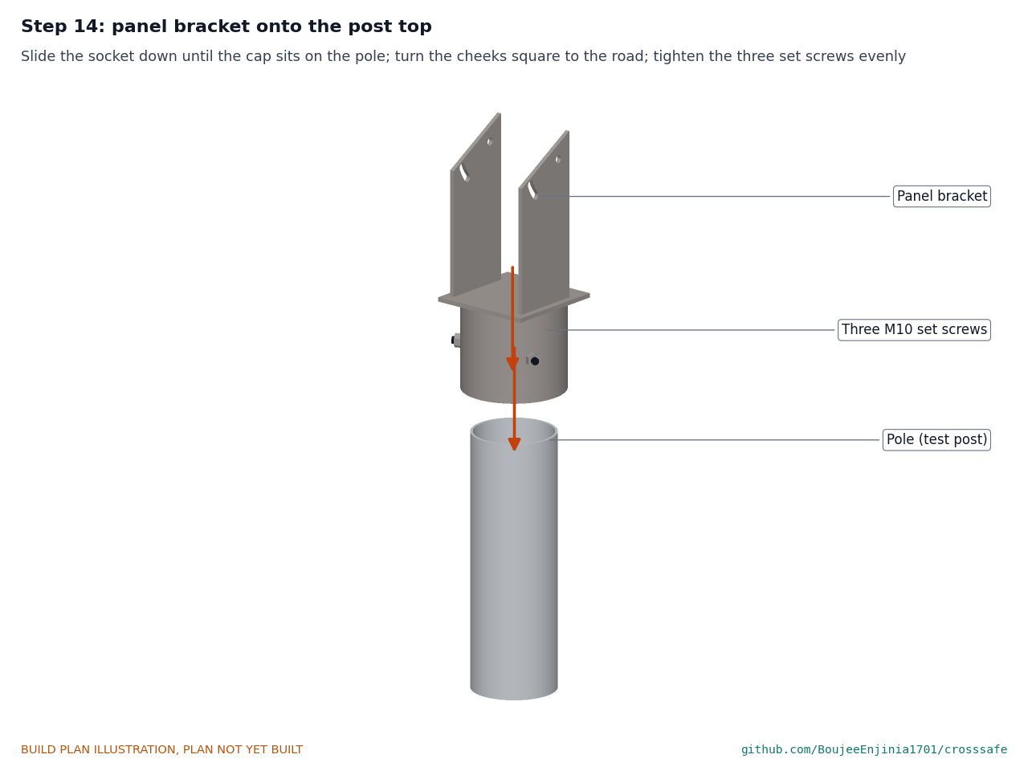
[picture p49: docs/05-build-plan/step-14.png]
Step 14


Slide the socket down until the cap sits on the pole. Turn it so the cheeks run square to the road, then tighten the three set screws evenly.

### Step 15: panel onto the bracket

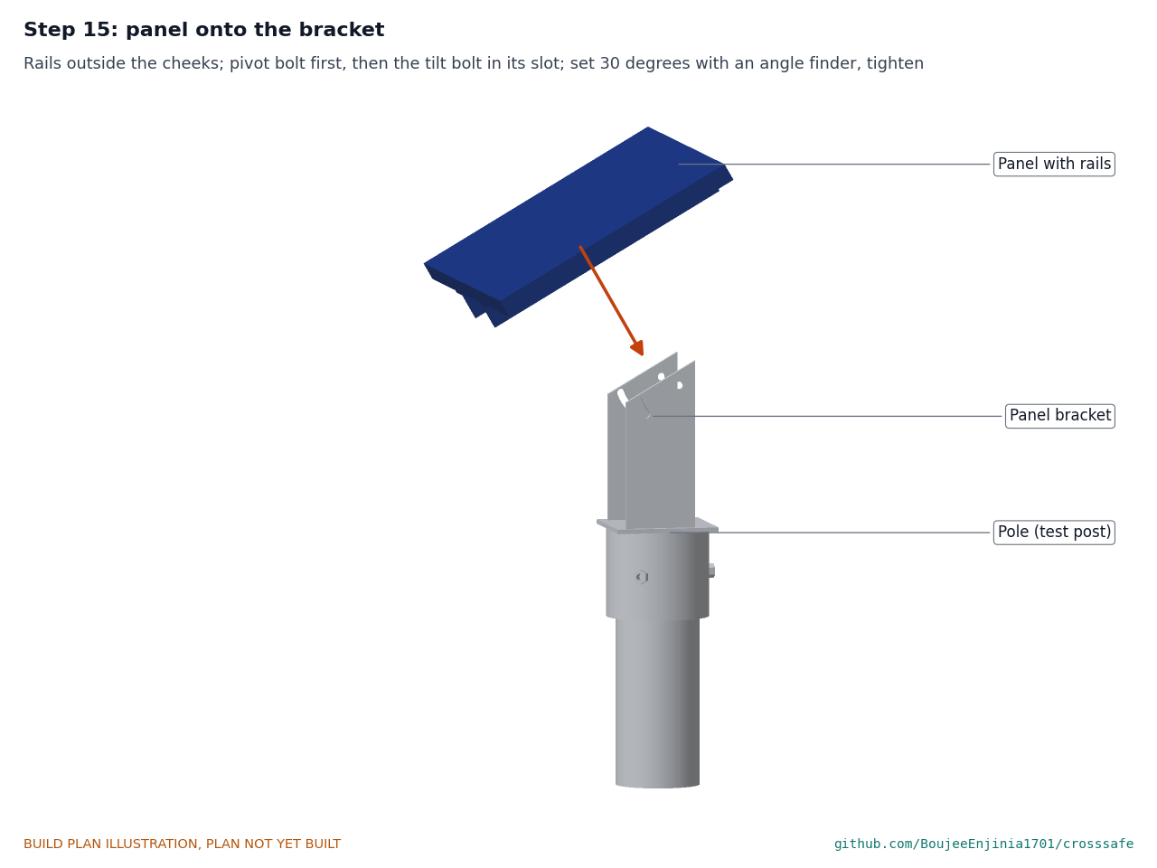
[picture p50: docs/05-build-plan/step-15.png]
Step 15


With a helper holding the panel, rails outside the cheeks: pivot bolts first, then the tilt bolts in their slots. Set 30° with an angle finder, the panel facing the equator, and tighten all four bolts.

### Step 16: cables into the enclosure

Step 16

Run each cable up the pole to the enclosure: the light bar, button and radar leads up from below, the panel lead down from the top. Fit the cable cover over them on the pole. Each cable in through its gland (section 3.2), the gland cap tightened on it; connect as Figure 8.

### Step 17: battery in, lid on

Step 17

**Hold point:** only after safety stops S1 to S4. Undo the strap's two screws, stand the battery on the floor against the internal plate, refit the strap, connect the battery leads to the fuse block, put the fuses in. Fresh desiccant pack; check the lid gasket is clean with no wire across it; lid on, its screws tightened evenly in a cross pattern.

### Step 18: sun shield

Step 18

Lower the shield over the enclosure from above, the antenna through its roof hole, flanges flat on the plate; four M5 security screws. **Hold point:** safety stop S7.

## 5. First checks

These are the checks a TRL 4 test report would record; this plan only lists them. Requirement numbers are those of CRS-REQ-001.

*Table 3. First checks.*

| Check | Requirement | How | Pass when |
| --- | --- | --- | --- |
| Heights | R10, R11, R14 | Tape from the post's bottom end (the sidewalk line) | Button centre 1,050; bar bottom 2,100; enclosure bottom 2,850; PIR underside 2,515, each within 10 |
| Saddles on the pole range | R10 | Seat one saddle and band on 60, 89 and 114.3 tubes | Both V faces touch each tube; the band closes with adjustment to spare |
| Band tension and grip | R9 | Banding tool's tension gauge; torque on the sign saddles with a lever arm | The tension and the slipping torque are recorded (the calculation assumes 1,000 N and a grip friction of 0.4) |
| Enclosure seal | R8 | Each washer under a lamp; gland caps tight on their cables | Every washer evenly squeezed; no gaps (the spray test comes later) |
| Charger settings | R6, R7, R8 | Bench supply at 18 V, 2 A limit, in place of the panel; battery out; read the charger's settings and output | LiFePO4 profile; charge voltage as the battery maker states (about 14.4 V); low-temperature cut-off set |
| First charge | R7 | Battery in, bench supply at 18 V, 2 A limit | Current flows; charging ends at the set voltage; battery stays under 45 °C |
| Flash pattern and time | R1, R4 | Press the button; film the heads; stopwatch | Wig-wag at 75 sequences per minute; flashing stops after the set time (12.8 s for 7 m); a second press extends it |
| Pilot light and button | R11 | Press with a force gauge; listen | Pilot light on while flashing; tone and tactile pulse; 22 N or less |
| Radar wake | R5 | Walk into the waiting zone; stand still 1 s | The PIR wakes the radar; the radar's presence output starts the flash |
| Fault indication | R12 | Unplug one head; unplug the antenna | The fault LED shows and the fault is logged; the bar never flashes continuously |
| Panel tilt | R7 | Angle finder; push the panel corners by hand | 30° give or take 1°; nothing moves at any joint |

## 6. Safety stops

Stop at each point. Carry on only when everything listed is true.

- **S1. Before the battery comes into the workshop.** Its voltage is 12.8 to 13.4 V; no swelling, dents or leaks; a datasheet from its maker. A charging spot ready on a non-combustible surface (ceramic tile or steel tray) with a fire extinguisher for electrical fires within reach.
- **S2. Before any fuse goes in.** With the battery out, the fuse block's battery terminals and every supply read open to ground. The battery leads' polarity matches the fuse block and the charger, checked with a meter, not by wire colour.
- **S3. Before any charging source is connected.** The charger is set to its LiFePO4 profile and its low-temperature cut-off; the panel input polarity is checked at the charger; the charger's maximum input is above the panel's open-circuit voltage at -20 °C.
- **S4. Before the battery is allowed to charge.** The charger settings check of section 5 passes on the bench supply. The supply's current limit is 2 A or less.
- **S5. First charge.** Attended the whole time, lid open, enclosure on the charging spot or the post on its trestles beside it; battery temperature checked every 15 minutes. Stop if the battery passes 45 °C or swells. Never bypass the charge protection to gain energy.
- **S6. Before the radio transmits.** The antenna is connected and matches the pilot region's band. Transmitting without an antenna can damage the radio.
- **S7. Before the post is stood up (outside this plan unless all of this is true).** Every band tensioned and every bolt tight; panel glass whole; sharp edges deburred. The post goes into a base or stand rated for at least 70 kg and a 3.7 m mast, with a lifting plan, two people and the area cleared. Nobody stands under the post while it is raised.
- **S8. Before any installation beside a road (outside this plan).** Road authority approval, the asset owner's permission for an existing pole, trained crews, traffic management and fall protection as local rules require, clear of overhead power lines; a qualified engineer has checked the post, saddles, bands, footing or host pole for about 2.6 kN·m at the sidewalk.

## 7. Tools, skills and workspace

**Tools.** Hacksaw with a 24 teeth per inch blade (or a bandsaw); bench vice with soft jaws and a radius block; bench drill or a drill in a stand; drills 3 to 12 and a 22 hole saw or step drill; step drill to 22; M4, M5 and M8 taps with their tap drills; jigsaw with a fine metal blade; flat, half-round and square files; deburring tool; scriber, engineer's square, protractor, steel rule and calipers; digital angle finder; hand sheet folder (or hardwood bars clamped in a vice) for 2 sheet up to 720 long; aviation snips; hand rivet tool and rivet nut tool; banding tool with tension gauge; socket and spanner set to 17; torque wrench; soldering iron; ferrule crimper and wire strippers; multimeter; bench power supply with an adjustable current limit (0 to 30 V, 0 to 3 A); two trestles and a tape measure. The panel bracket needs a welder (MIG or stick) or a fabricator who will weld it.

**Skills.** Basic metalwork (marking out, sawing, drilling, filing, tapping, folding sheet), through-hole soldering and crimping, safe use of a bench power supply and care with lithium cells. The bracket welds should be made by a competent welder. All circuits are extra-low voltage: 12.8 V at the battery and under about 22 V from the panel. The bench supply must be a certified, undamaged unit; no mains wiring is part of this build.

**Workspace.** A bench about 1.5 x 0.7 m, and floor space about 4.5 x 1.5 m for the post on its trestles; a metalwork corner kept apart from the electronics so chips stay off the modules; the charging spot of S1.

**Personal protective equipment.** Safety glasses for cutting, drilling and soldering; cut-resistant gloves for sheet, the sign and the panel; hearing protection when sawing; safety boots when handling the post; no gloves near a turning drill; welding mask, gloves and jacket for the bracket.

## 8. Where the numbers come from

- Model and constructability checks: `cad/src/model.py` (`python cad/src/model.py --check`); STEP and STL exports in `cad/step/` and `cad/stl/`.
- Pictures: `cad/src/build_plan_media.py`, using `.kit/build_views.py`; written to `docs/05-build-plan/` and `cad/drawings/CRS-DWG-101` to `CRS-DWG-109`.
- General arrangement: `cad/drawings/CRS-DWG-001.pdf`, Rev P4.
- Calculations: `docs/04-calcs/01-sizing.md` (CRS-CAL-001 v0.4) and `docs/04-calcs/sizing.py`; heights [F1], pole range [F2], wind and clamps [G1] to [G8], cost [H1] to [H3].
- Bill of materials: `bom/bom.csv`.
- Decisions: `docs/decisions/0003-design-for-construction.md` (CRS-DDR-003), with CRS-DDR-001 and CRS-DDR-002; decisions made in `docs/06-design-decisions.md` (CRS-DEC-001).
- Requirements: `docs/03-requirements.md` (CRS-REQ-001 v0.6).

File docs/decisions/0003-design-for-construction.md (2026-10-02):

---
doc_id: CRS-DDR-003
title: CrossSafe design for construction
project: CrossSafe
doc_type: Design decision record
version: "0.3"
status: Draft
date: '2026-10-02'
author: Amish Chadha
license: CERN-OHL-S-2.0
revisions:
- version: "0.1"
  date: '2026-09-30'
  author: Amish Chadha
  change: Changes that make the concept physically buildable, with the reason for each; made under Amish's 2026-09-30 instruction to make the design physically buildable; open for his review
- version: "0.2"
  date: '2026-10-01'
  author: Amish Chadha
  change: Budget treated as a value-engineering target
- version: "0.3"
  date: '2026-10-02'
  author: Amish Chadha
  change: "Accepted by Amish on 2026-10-02, including the recommendations for A2 and A3"
---

# 0003: Design for construction

- **Date:** 2026-09-30
- **Status:** accepted. Amish, 2026-10-02: "i approve your recommendations for all 555 open decisions." This covers every change in Tables 1 and 2 and the recommendations for A2 and A3 in Table 3, which are now decided as recommended and recorded in the design decisions register (`docs/06-design-decisions.md`, CRS-DEC-001).

## Context

On 2026-09-30 Amish approved the build plan format and asked for it across every repo, writing: "If you are realising that the design cannot be built as per concept - fix the design assumptions to match and be physically feasible as you draw the illustrations." The CrossSafe model of CRS-DDR-002 showed what the beacon does, with the right heights, sizes and wind areas, but almost nothing in it was fixed to anything. The pole clamps were 8 mm thick rings that passed straight through every bracket they were meant to hold; each bracket touched the round pole along a single line; the sign stood on two solid blocks 92 mm deep; the battery, charger and controller floated inside the enclosure; the sun shield had no fixing; and the panel's tilt plate hung 7.5 mm below the panel and 10 mm above its stem, touching neither. A build123d check of the concept model found the parts that overlapped or floated; Table 1 lists them as P1 to P11.

The changes keep what CrossSafe does: the same sign, light bar, LED heads, flash pattern, button, radar, PIR, panel, battery, enclosure, sun shield and radio, at the same heights above the sidewalk (button 1,050 mm, light bar bottom 2,100 mm, sign 2,250 to 3,311 mm, enclosure 2,850 to 3,150 mm, radar 2,600 mm, panel centre 3,930 mm). Nothing here changes the pitch or the safety case. Every change is in `cad/src/model.py`, which now runs 101 constructability checks on the existing-pole kit and 103 on the new-post variant (`python cad/src/model.py --check`): no two of the 55 components (56 with the new post) overlap, every joint that must touch does, the stated clearances hold, both ends of the pole range seat in the saddle's V, and the heights of R14 hold. All pass.

## Decision

*Table 1. Changes made to the model, the BOM and the calculations.*

| # | Problem in the concept | Change made | Why this way |
| --- | --- | --- | --- |
| P1 | The seven "pole clamps" were rings 8 mm thick and 30 mm wide drawn round the pole. Each passed through the bracket it was meant to hold (light bar block, sign saddles, enclosure back plate, button station, radar arm), and every bracket met the round pole along one line. | One part holds everything to the pole: eight identical **keyed pole saddles** (line 20), each a block 80 wide, 40 deep and 60 tall sawn from 80 x 40 mm aluminium bar, with a 120° V in the back whose faces are keyed with saw cuts, a 21 x 1 mm band groove across the front and two tapped M8 holes 20 mm above and below the groove. A 19 x 0.76 mm stainless band (line 13) runs round the pole and across the saddle's front in the groove; the part fixed to the saddle covers the band. | Tightening the band pulls the V onto the pole; the pole touches both V faces 6.4 mm inside the back corners on a 114.3 mm pole and 20 mm inside on a 60 mm pole, so one saddle fits the whole R10 range. One part made eight times keeps the workshop simple. 19 x 0.76 mm is the common size of stainless banding with a buckle. |
| P2 | The sign stood 92 mm in front of the pole on two solid blocks 92 x 80 x 60 mm (about 1.2 kg of aluminium each), with nothing that made them or fixed them. | The sign lies flat on the front of its two saddles, 28.6 mm in front of the pole surface, held by two M8 security bolts into each saddle (four 9 mm holes on the sign's vertical centre line). The sign is now 63.4 mm nearer the pole. | The saddle is the stand-off. The light bar is still directly under the sign point, 20 mm below it; it now stands 70 mm proud of the sign's plane, which IA-21 allows. |
| P3 | The light bar was a solid box fixed by a 16 x 80 x 100 mm block that touched the pole on one line; the LED heads were 8 mm slabs stuck on its faces. | A folded 2 mm aluminium channel (back, top, front, with 10 mm inward lips), a screwed bottom cover with a cable gland and two riveted end caps. Each head's flange sits on the outside of its wall over a 128 x 50 mm cut-out, with its body inside. The back wall bolts to the bar's saddle with two M8 bolts put in from inside, reached by taking the cover off. | A housing that can be folded, opened and sealed. The bar's back face moves 12.6 mm further from the pole (onto the saddle); its height, length and the head positions are unchanged. |
| P4 | The enclosure was a hollow box held off the pole by a 5 x 120 x 200 mm block touching the pole on one line; the battery, charger and controller floated inside it. | A 4 mm aluminium **mounting plate** (line 21), 350 x 300 mm with a 90 x 90 mm tab above and below, bolted to two saddles by its tabs. The enclosure hangs on its front by the box maker's four lugs (M5 screws, nyloc nuts behind). Inside, the box's own internal plate sits on four bosses; the charger, controller and a fuse block stand on it on 6 mm stand-offs; the battery stands on the floor against it under a bent aluminium **battery strap** (line 23). | The box back stays sealed. The enclosure's back face is now 32.6 mm from the pole surface (was 5 mm), so the enclosure moves 27.6 mm further out; its height and size are unchanged. |
| P5 | (Found in checking) With the saddles behind the enclosure, the bolts holding the plate to them would be hidden behind the box. | The saddles sit on the plate's tabs, above and below the box: their bolts are at 3,190 and 3,230 mm, above the shield roof, and at 2,770 and 2,810 mm, below the box. | The enclosure, plate and shield can be bolted to the pole, and taken off it, as one unit. |
| P6 | The sun shield had no fixing. | A 15 mm flange folded out along the plate edge of each side sheet lies flat on the mounting plate and takes two M5 security screws into tapped holes. The roof's air gap stays open toward the post above the plate's top edge; the bottom stays open. | The 25 mm air gap at the back, sides and roof is unchanged, so the thermal result of CRS-CAL-001 stands. |
| P7 | The radar sat on a 24 mm rod that touched the pole on one line; the PIR hung under the radar. | A **radar arm** (line 22): 40 x 5 mm aluminium bar bent to an L. The short leg stands on its saddle (two M8 bolts); the long leg runs 251 mm toward the kerb with the radar screwed on top of its end and the PIR under it. | The radar stays at 2,600 mm and 240 mm from the pole surface. The PIR's underside drops 5 mm, to 2,515 mm, still above R14's 2.5 m line. |
| P8 | The panel bracket was a sleeve over the post top, a block standing on it and a tilt plate 7.5 mm below the panel and 10 mm above the block, touching neither. | A welded steel **panel bracket** (line 7): a 139.7 x 4 mm socket over the post top with a 6 mm cap that rests on the pole, three welded M10 nuts with security set screws, and two 6 mm cheeks standing on the cap. Two 40 x 40 x 4 mm aluminium **rails** bolt across the panel frame's back lip and to the outside of the cheeks by a pivot bolt and a bolt in a 20° tilt slot. | Every joint is face to face and bolted; the tilt can be set from 20 to 40° as the BOM always said. The panel's centre, size and 30° tilt are unchanged. |
| P9 | The push-button station touched the pole on one line; the instruction plate stood flat against a round pole with no fixing. | The station bolts to its own saddle at 1,050 mm; the instruction plate to a saddle of its own at 1,300 mm (two M8 bolts). | This is why there are eight saddles and bands, not seven. |
| P10 | The enclosure's bottom face had no positions for its cable glands, and gland nuts inside would have sat under the battery. | Four M20 glands (panel, light bar, button, radar and PIR) in two rows, 40 and 100 mm from the back face, 105 mm each side of the centre line, clear of the battery; the membrane vent at the lid end. Glands are now in line 15. | Each gland and its inside nut clear the battery by at least 5 mm. |
| P11 | On new posts the anti-rotation bolt ended inside the saddle, with nothing holding it. | The M10 bolt replaces the upper sign saddle's upper M8 bolt: through the sign, the saddle (drilled through 10.5 mm) and both post walls, nyloc nut behind. Its length is 160 mm (was 200 mm). | The bolt still carries the sign's torsion as two bearing loads on the post walls (CRS-CAL-001, [G6b], unchanged). |

*Table 2. Knock-on changes.*

| Item | Change | Reason |
| --- | --- | --- |
| Wind | Along the road, the enclosure group now includes the mounting plate's edges beside the shield and its two tabs: base moment 3,521 N·m (was 3,434), the 114.3 mm post at 45 % of yield (was 44 %), embedment needed 1,791 mm (1,800 modelled), moment added to an existing pole 2,601 N·m (was 2,514). R9's status is unchanged. | Follows the model (CRS-CAL-001 v0.4, [G1] to [G8]). |
| Cost | Lines 1, 7, 13, 15, 19 and 20 changed and lines 21 to 23 added: $360.00 per assembly on an existing pole (was $332.00), $433.00 with a new post (was $405.00); $720.00 and $866.00 per crossing. **R15 is now over the value-engineering target on paper: $10.00 over the $350 target, and $20.00 over its $700 per crossing.** | Parts that every buildable version needs; see the Value engineering section of the design decisions register. |
| Heights | PIR underside 2,515 mm (was 2,520 mm). Everything else unchanged. | P7. |
| Drawing | CRS-DWG-001 Rev P4; making sketches CRS-DWG-101 to 109 added. | Follows the model. |
| Documents | CRS-CAL-001 v0.4, CRS-PRC-001 v0.6, CRS-REQ-001 v0.6, `bom/bom.csv` (23 lines), `bom/bom-notes.md`. | Follows the model. |
| Heat, energy, radio, light | Unchanged. The enclosure, shield and air gaps keep their sizes; nothing electrical changed. | |

*Table 3. Proposed, then accepted by Amish as recommended on 2026-10-02.*

| # | Question | Options | Recommendation |
| --- | --- | --- | --- |
| A2 | The post-top socket fits poles of about 114 mm with an open or capped top. Existing poles in R10's range (60 to 114.3 mm), or poles that are taller or carry a luminaire, cannot take it. | (a) reducing sleeves for 76 and 89 mm poles; (b) a side-of-pole panel arm on two more saddles; (c) limit the existing-pole kit to free-topped poles of about 114 mm. | (b), designed when the pilot site's poles are known (O1); the prototype uses (c). Accepted 2026-10-02. |
| A3 | The changes in Table 1 are visible: the sign sits nearer the pole, the light bar stands proud of it, the saddles, bands, plate and bracket are new. | (a) accept them; (b) ask for a different arrangement of any of them. | (a). The photoreal renders and the appearance model then need updating on Amish's Mac. Accepted 2026-10-02. |

## Consequences

- `design_state: constructable` in `project.yaml`. The build plan CRS-BLD-001 (`docs/05-build-plan.md`) shows every component and step in pictures generated from the model (`cad/src/build_plan_media.py`).
- Cost is reported against the value-engineering target: USD 350 (a hypothetical control target, not a limit) against an estimated USD 360.00 for the constructable design, USD 10.00 over; cost drivers and savings worth trying are in the register.
- Requirement status: one over its value-engineering target (R15, cost), one at risk (R9, small poles, unchanged), three not verifiable at TRL 3, four met on paper, six met by design (CRS-CAL-001 v0.4).
- The photoreal renders (`media/render-*.png`), `media/card.png`, `media/social-preview.png` and the appearance model `cad/src/product_model.py` still show the concept sign stand-off, clamps and bracket; they are stale until regenerated on Amish's Mac, where Blender is.
- The keyed saddle's grip friction (0.4) and the band tension (1,000 N) remain assumptions to be measured at TRL 4, which is on hold. Until a slip-torque test confirms them, the existing-pole kit is limited to poles of 76 mm and larger (CRS-DDR-002, N1, decided 2026-10-02).
- With A2 accepted, the prototype's panel socket is for free-topped poles of about 114 mm; a side-of-pole panel arm is designed once the pilot site's poles are known.

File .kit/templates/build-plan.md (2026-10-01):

---
doc_id: PRJ-BLD-001
title: Project prototype build plan
project: Project name
doc_type: Build plan
version: "0.1"
status: Draft
date: YYYY-MM-DD
author: Amish Chadha
license: CERN-OHL-S-2.0
revisions:
  - version: "0.1"
    date: YYYY-MM-DD
    author: Amish Chadha
    change: First build plan; design made constructable
---

# Project prototype build plan

**Plan, not yet built.** How to build the first proof-of-concept prototype, component by component. Building and testing to it is TRL 4 work. Decisions still to be made are kept in the design decisions register (`docs/06-design-decisions.md`), not here.

## 1. What you are building

Every component, pulled apart and numbered in build order

One short paragraph: what the prototype is, how many components, which are made and which are bought, and the main ways they are made.

## 2. What changed to make it buildable

| Component | The concept had | The buildable design has | Why |
| --- | --- | --- | --- |

## 3. Making the components

### 3.1 Component name

Making sketch

**What it is and what it is made from.**

**How to make it.**

1. Mark out ...
2. Cut ...

**How it fits the parts next to it.**

Close-up of the joint

**Check before moving on.**

## 4. Putting it together

### Step 1: ...

Step 1

## 5. First checks

| Check | Requirement | How | Pass when |
| --- | --- | --- | --- |

## 6. Safety stops

## 7. Tools, skills and workspace

## 8. Where the numbers come from

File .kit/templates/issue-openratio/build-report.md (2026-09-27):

---
name: Build report
about: Tell us what happened when you built, printed or tested part of this design
title: "Build report: "
labels: build-report
---

This is a research and educational prototype, not a medical device. It is a TRL 3 concept and is not released for fabrication. If you build any part of it, you do so at your own risk. Reports help everyone.

**What you built** (part, sub-assembly or test)

**Materials, tools and settings**

**What worked**

**What did not work, with photos or measurements if you have them**

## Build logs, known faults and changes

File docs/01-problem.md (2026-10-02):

---
doc_id: CRS-PRB-001
title: CrossSafe problem statement
project: CrossSafe
doc_type: Problem statement
version: "0.5"
status: Draft
date: '2026-10-02'
author: Amish Chadha
license: CERN-OHL-S-2.0
revisions:
- version: "0.1"
  date: '2026-09-25'
  author: Amish Chadha
  change: Initial scaffold
- version: "0.2"
  date: '2026-09-25'
  author: Amish Chadha
  change: Populate to TRL 2 (problem, users, context, constraints, out of scope, prior work)
- version: "0.3"
  date: '2026-09-25'
  author: Amish Chadha
  change: TRL 3 update; budget scope per CRS-DDR-001 D1, IA-21 details checked, open questions linked to CRS-DDR-001
- version: "0.4"
  date: '2026-10-01'
  author: Amish Chadha
  change: Budget treated as a value-engineering target
- version: "0.5"
  date: '2026-10-02'
  author: Amish Chadha
  change: "Pilot partner open question answered with the selection rule and first candidate decided on 2026-10-02"
---

# CrossSafe problem statement

Pedestrians die at unsignalized crossings, and full traffic signals are costly and slow to approve. A driver who does not see a waiting pedestrian, or sees them too late, does not yield. CrossSafe is an open, solar-powered beacon that warns drivers only when someone is actually waiting to cross, at crossings near schools, markets and bus stops that will not get a full signal. Design with, not for: requirements must come from co-design sessions with road users and the road authority through a local partner.

## The problem

About 1.19 million people die on the world's roads each year, and pedestrian deaths rose 3 % to about 274,000 between 2010 and 2021, 23 % of the total ([WHO, 2023](https://www.who.int/news/item/13-12-2023-despite-notable-progress-road-safety-remains-urgent-global-issue)). Nine in ten road deaths occur in low- and middle-income countries ([WHO, 2023](https://www.who.int/news/item/13-12-2023-despite-notable-progress-road-safety-remains-urgent-global-issue)), and road traffic injuries are the leading cause of death for children and young people aged 5 to 29 ([WHO fact sheet](https://www.who.int/news-room/fact-sheets/detail/road-traffic-injuries)).

High-income countries are not exempt. In the United States, 7,314 pedestrians were killed in 2023; 74 % of those deaths happened away from intersections and 77 % in the dark ([NHTSA, 2025](https://crashstats.nhtsa.dot.gov/Api/Public/ViewPublication/813727)). In Great Britain, pedestrians were 25 % of the 1,624 road deaths in 2023 ([Department for Transport](https://www.gov.uk/government/statistics/reported-road-casualties-great-britain-annual-report-2023/reported-road-casualties-great-britain-annual-report-2023)).

The marked crossing without a signal is where the pedestrian's right of way and the driver's attention most often fail to meet. Three gaps make it hard to fix:

1. **Cost and approval.** A full signal needs a mains connection, a cabinet, foundations and an engineering study. Many crossings will never qualify or be funded.
2. **Static signs fade into the background.** A sign that is always there says nothing about whether someone is waiting now. Warning lights that flash all day teach drivers to ignore them.
3. **Power and maintenance.** Many crossings that need help are on roads without a convenient mains supply, and closed commercial beacons are expensive to buy and hard to repair locally.

There is good evidence that an active, pedestrian-triggered warning works. The US Federal Highway Administration lists the rectangular rapid flashing beacon (RRFB) as a proven safety countermeasure that can reduce pedestrian crashes by up to 47 % and raise driver yielding rates to as high as 98 %, depending on speed, lanes, crossing distance and time of day ([FHWA](https://highways.dot.gov/safety/proven-safety-countermeasures/rectangular-rapid-flashing-beacons-rrfb)). CrossSafe asks whether an open, solar, garage-buildable design can bring that kind of device to crossings and communities that cannot buy one today.

## Users and context

| User | Need | Context |
| --- | --- | --- |
| Pedestrian, including children, older people and people with disabilities | Cross safely, with drivers stopping; clear confirmation that the warning is on | School run, market days, bus stops, often at dusk or in the dark |
| Driver | Early, unmistakable warning only when someone is waiting | Urban and peri-urban roads, 30 to 60 km/h, glare and rain |
| School or market community | A safer crossing without waiting years for a signal | Parent groups, school boards, market associations as local champions |
| Road authority or municipal engineer | A device that meets local rules, is reliable, and costs little to maintain | Approval, installation permits, asset registers |
| Local technician | Install, service and repair with ordinary tools and parts | Hand tools, a ladder or bucket truck, a multimeter |

### Operating environment

- **Site:** a marked, unsignalized crossing on a two-lane road, about 7 m kerb to kerb, with a sidewalk or verge on each side. Wider roads need a median assembly (out of scope for the first concept).
- **Climate:** ambient -20 to +50 °C across target regions, direct sun on the enclosure, heavy rain, dust and road spray.
- **Power:** no mains assumed; solar resource from about 2.5 peak sun hours per day in a poor month (estimate for mid latitudes and tropical rainy seasons) upward.
- **Use:** up to about 300 activations per day at a busy school or market crossing (estimate, to be checked in co-design and site counts).
- **Threats:** theft of panels and batteries, vandalism, vehicle strikes on the pole.

## Constraints

- Garage-buildable prototype of one beacon assembly on an existing pole, a value-engineering target of $350 USD in parts (`project.yaml`; scope adopted for TRL 3 in CRS-DDR-001 D1, open for Amish's review). A crossing needs two assemblies; a value-engineering target of $750 applies to a two-sided site trial when one starts (CRS-DDR-002, O2).
- Built from off-the-shelf parts: standard signs, LED modules, a small solar kit, a LiFePO4 battery, an IP65 box and a common microcontroller.
- Needs road authority approval before any use on a public road. Local rules on colors, flash patterns, sign design and mounting heights take precedence over anything in this repo.
- Privacy: counts and activation events only; no images or audio are recorded or leave the device.

## Out of scope

- Full traffic signals, pedestrian hybrid beacons and any device that shows a red indication or stops traffic.
- Enforcement features such as speed cameras.
- Crossings of more than one lane per direction, where a beacon alone is not enough and a median refuge or signal is usually needed.
- Certification to any national standard; the repo can only document how the design relates to one.

## Prior work

- **RRFB.** Amber, rectangular, pedestrian-activated beacons mounted with the crossing warning sign. In the United States they are covered by FHWA Interim Approval IA-21 (20 March 2018), which sets the minimum indication size (at least 5 in wide by 2 in high), daytime intensity to the SAE J595 Class 1 yellow peak, a wig-wag flash pattern at 75 flashing sequences per minute, automatic night dimming, pushbutton or passive detection, an optional pilot light for pedestrians, and use only at uncontrolled marked crosswalks ([FHWA IA-21](https://mutcd.fhwa.dot.gov/resources/interim_approval/ia21/index.htm)). Solar RRFBs are sold commercially; they are closed designs.
- **Evidence of effect.** FHWA's proven safety countermeasure summary for RRFBs (see above) gives the crash and yielding figures used in this repo.
- **Sibling designs in the lab.** FieldNode (a sibling Design Molecule repo) is the lab's shared solar sensor node (6 W panel, 3.2 V LiFePO4 cell, LoRaWAN). Its radio and logging core (an STM32WL-class module) is reused for the CrossSafe controller, but its power stage is too small for the LED load; see CRS-PRC-001 and CRS-DDR-001 D7.

## Open questions

- [ ] Which pilot country and road authority, and which rules apply there (colors, flash pattern, sign type, mounting height)? Decided 2026-10-02 as a selection rule: a United States city traffic engineering department with a Safe Routes to School or Vision Zero programme; first candidate to approach, a North Texas city near the team (CRS-DEC-001).
- [ ] Is passive detection allowed and trusted locally, or should the button be the only trigger?
- [ ] How many activations per day at the candidate sites, and how dark are they at the busy times?
- [ ] How much theft and vandalism should the design expect, and at what mounting height is the battery safe?

## User research and co-design

This design is for communities the author is not part of, so requirements come from the people who will use it.

- [ ] Identify a local partner organization (Helpful Engineering network, NGO or university)
- [ ] Run co-design sessions with intended users; record who, where and what was learned
- [ ] Validate load, distance, terrain and cost assumptions in the field
- [ ] Revise requirements (REQ) from findings before freezing the design

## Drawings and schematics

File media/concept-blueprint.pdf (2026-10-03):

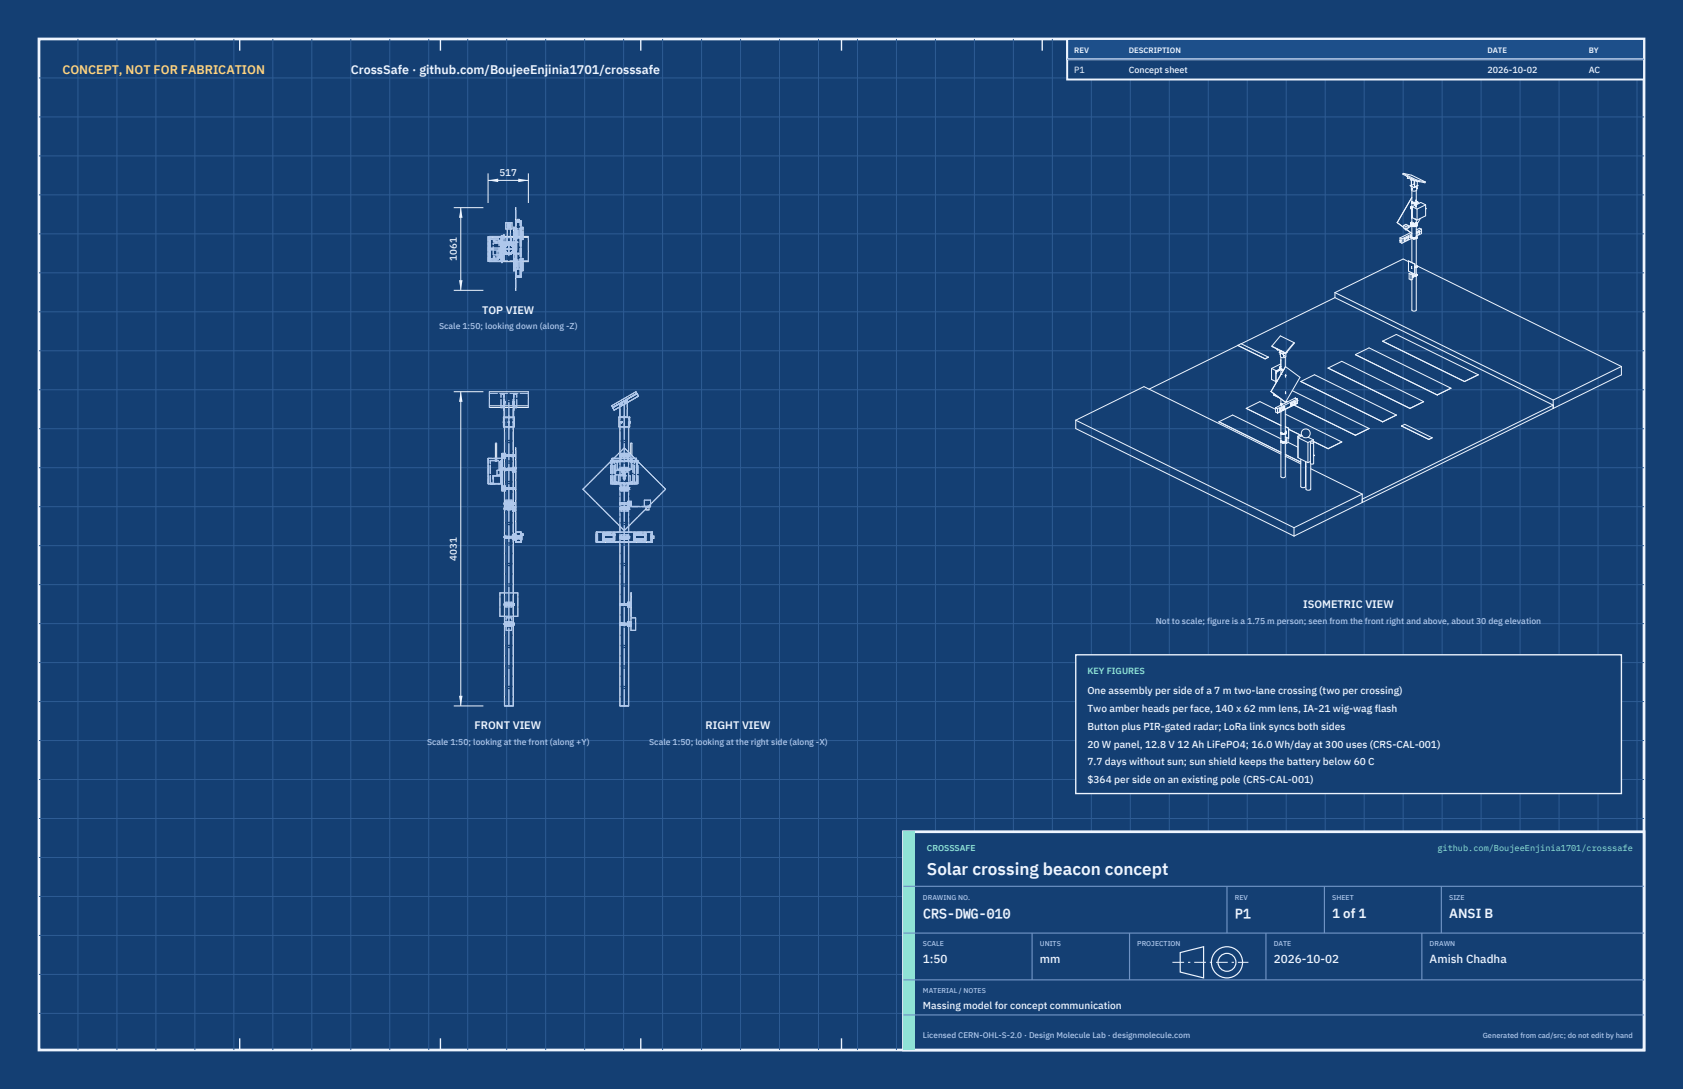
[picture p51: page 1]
CONCEPT, NOT FOR FABRICATION; CrossSafe · github.com/BoujeeEnjinia1701/crosssafe; FRONT VIEW; TOP VIEW; RIGHT VIEW; ISOMETRIC VIEW; REV; DESCRIPTION; DATE; Concept sheet; CROSSSAFE; github.com/BoujeeEnjinia1701/crosssafe; DRAWING NO. CRS-DWG-010; REV P1; SHEET 1 of 1; SIZE ANSI B; SCALE 1:50; UNITS mm; PROJECTION; DRAWN Amish Chadha; Licensed CERN-OHL-S-2.0 · Design Molecule Lab · designmolecule.com; Generated from cad/src; do not edit by hand

Scale 1:50; looking down (along -Z)

Not to scale; figure is a 1.75 m person; seen from the front right and above, about 30 deg elevation

KEY FIGURES
One assembly per side of a 7 m two-lane crossing (two per crossing)
Two amber heads per face, 140 x 62 mm lens, IA-21 wig-wag flash
Button plus PIR-gated radar; LoRa link syncs both sides
20 W panel, 12.8 V 12 Ah LiFePO4; 16.0 Wh/day at 300 uses (CRS-CAL-001)
7.7 days without sun; sun shield keeps the battery below 60 C
$364 per side on an existing pole (CRS-CAL-001)

Scale 1:50; looking at the front (along +Y)

Scale 1:50; looking at the right side (along -X)

Solar crossing beacon concept

MATERIAL / NOTES
Massing model for concept communication

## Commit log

2026-09-25 Initial scaffold: standard open hardware layout, CERN-OHL-S v2 + MIT licenses
    Claude-Session: https://claude.ai/code/session_01XuhhSU4W6fYhgCfURbrkut
    [bom.csv]
2026-09-26 Populate to TRL 2: problem, requirements, precis, concept media, BOM and README use cases
    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
    [bom.csv]
2026-09-26 Advance to TRL 3: DDR-001, CAL-001 sizing, parametric model with STEP/STL, GA drawing, priced BOM; TRL 4 on hold
    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
    [bom.csv, crosssafe-assembly.step, crosssafe-assembly.stl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]
2026-09-26 Accept all recommendations (DDR-002), switch footer to designmolecule.com, add README write-up with new inspiration point
    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
    [bom.csv, crosssafe-assembly.step, crosssafe-assembly.stl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]
2026-09-27 Product appearance model and photoreal renders
    Adds cad/src/product_model.py (appearance model for renders only, all main
    dimensions from model.py) and Blender renders in media/render-*.png,
    captioned with the project, repository and viewing direction. README leads
    with the product render; trl stays 3.
    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
2026-10-01 Image quality pass: legible exploded views, flow diagrams and drawing sheets
    Kit 1.6.1 image layout: the parts list sits in its own column, number bubbles sit on visible parts and never overlap, small parts get a leader, pictures are cropped to the subject, flow labels keep numbers with their units, and sheet captions and the revision table no longer overprint. Concept images, blueprint and general arrangement sheet regenerated; repo-specific labels moved clear of other text and lines.
2026-10-01 Kit 1.7.0: constructable design, illustrated build plan and design decisions register
    The design is now constructable: every part can be made and fits its neighbours, with each change recorded in a Design for construction decision record (made under Amish's 2026-09-30 instruction; ope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
    [bom.csv, crosssafe-assembly.step, crosssafe-assembly.stl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]
2026-10-01 Budget treated as a value-engineering target
    Amish, 2026-10-01: the budget is a hypothetical control target that keeps the design on a value-engineering lens, not a spending limit. Documents now state the value-engineering target and the estima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
2026-10-02 Record Amish's approval of the open-decision recommendations
    Amish approved the recommendation on every open decision in the design decisions register ("i approve your recommendations for all 555 open decisions.", 2026-10-02). Each decision is moved to Decisio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
2026-10-03 Carry approved follow-ups into the design and redo photoreal renders
    Amish approved the follow-up actions from the open-decision sign-off ("APPROVED CHANGES, COMPLETE THESE", 2026-10-02), the design-for-construction change tables in ten repos, the last wave's open dec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
    [bom.csv, crosssafe-assembly.step, crosssafe-assembly.stl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]
2026-11-01 Kit 1.9.1 upgrade: pipeline documents and detailed CAD for every option
    STEM check with fixes under the standing instruction and an independent
    review, concept options scored against the user requirements, URS, PRS,
    RTM, REG, FEA, RSK, MKT, PLN and DDR, every option modelled at D3 with
    cad/fidelity.json passing, and the concept options picture rendered with
    Blender Cycles on Amish's Mac. Concept choices stay proposed, awaiting
    Amish.
    Claude-Session: https://claude.ai/code/session_01LppsZSzPTJWTBAV5wh1Goq

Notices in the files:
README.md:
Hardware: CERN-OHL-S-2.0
